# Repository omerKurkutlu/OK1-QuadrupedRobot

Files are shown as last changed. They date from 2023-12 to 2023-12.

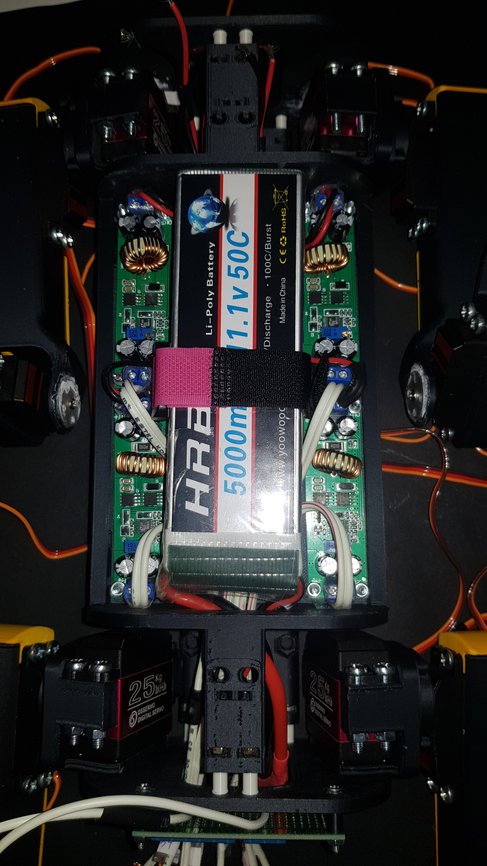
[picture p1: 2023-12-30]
media/3.jpg

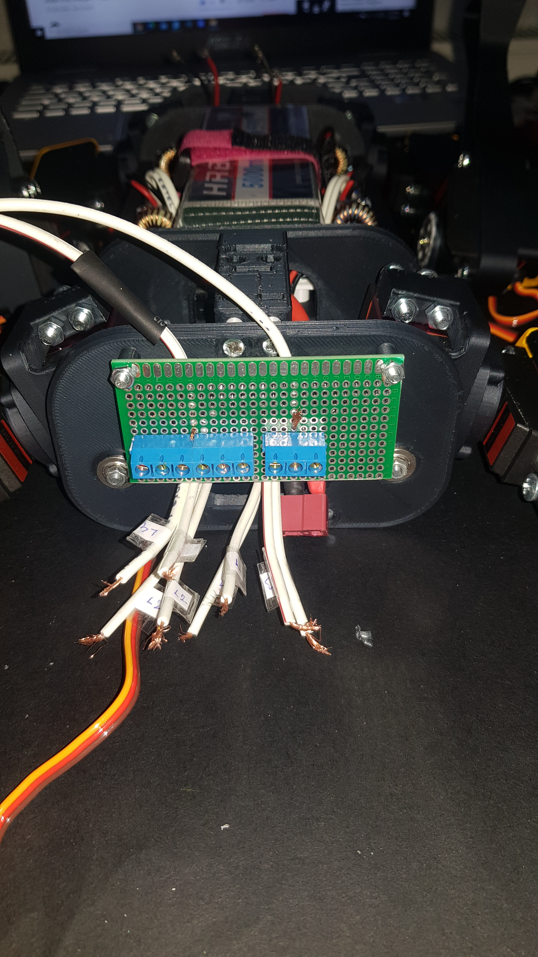
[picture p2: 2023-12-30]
media/4.jpg

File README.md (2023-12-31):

# Quadruped Robot Project

1. [Overview](#overview)
2. [Features](#features)
3. [Folder Structure](#folder-structure)
4. [Enjoying OK1 Robot (Video)](#enjoying-ok1-robot-video)
5. [Getting Started for ROS and Gazebo](#getting-started-for-ros-and-gazebo)
    - [Clone the Repository](#1-clone-the-repository)
    - [Navigate to the ROS Workspace](#2-navigate-to-the-ros-workspace)
    - [Build the ROS Workspace](#3-build-the-ros-workspace)
    - [Source the Workspace](#4-source-the-workspace)
    - [Launch the Robot](#5-launch-the-robot)
6. [OK1 Robot Simulation (Video)](#ok1-robot-simulation-video)
7. [3D Printing Files and Assembly Instructions](#3d-printing-files-and-assembly-instructions)
    - [OK1 Printings](#ok1-printings)
    - [Remote Controller Printings](#remote-controller-printings)
    - [ELECTRONICS for OK1](#electronics-for-ok1)
    - [ELECTRONICS for Remote Controller](#electronics-for-remote-controller)
    - [HARDWAREs](#hardwares)
    - [EXTERNALS](#externals)
8. [Electronics Assembly](#electronics-assembly)
9. [Wiring Instructions](#wiring-instructions)
10. [Arduino Code Compiling and Uploading](#arduino-code-compiling-and-uploading)
11. [Remote Controller Usage Instructions](#remote-controller-usage-instructions)

## Overview

This project implements a quadruped robot named OK1 using Arduino, with support for ROS and Gazebo simulation. The robot is designed to walk on four legs and can be controlled both physically and through software.

## Features

- Quadruped robot hardware based on Arduino Mega 2560.
- A Remote Controller
- ROS (Robot Operating System) support for high-level control and communication.
- Gazebo simulation environment for testing and development.
- Modular and extensible design for customization.

## Folder Structure

- **`/CAD-Hardware`**: Contains 3D printing files for the robot parts.
- **`/Arduino`**: Arduino code for controlling the robot.
- **`/ROS_ws`**: ROS packages for communication and control.
- **`/media`**: Some useful images for implementation.

render0

## Enjoying OK1 Robot (Video)

We are enjoying OK1 Robot. (https://www.youtube.com/watch?v=7ynvawNMwWk&ab_channel=%C3%96merKurkutlu)

## Getting Started for ROS and Gazebo

Follow these steps to get started with the ROS and Gazebo simulation environment for the OK1 Quadruped Robot:

1. **Clone the Repository:**

    ```bash
    git clone https://github.com/omerKurkutlu/OK1-QuadrupedRobot.git
    ```

2. **Navigate to the ROS Workspace:**

    ```bash
    cd ROS_ws
    ```

3. **Build the ROS Workspace:**

    ```bash
    catkin_make
    ```

4. **Source the Workspace:**

    ```bash
    source ./devel/setup.bash
    ```

5. **Launch the Robot:**

    - For Rviz Visualization:

        ```bash
        roslaunch ok1_moveit_config demo.launch
        ```

    - For Gazebo Simulation:

        ```bash
        roslaunch ok1_moveit_config demo_gazebo.launch
        ```

These commands will set up the necessary environment for ROS and Gazebo, allowing you to visualize and simulate the OK1 Quadruped Robot. Make sure to follow the instructions carefully, and feel free to explore the ROS workspace for additional details.
 
r1

## OK1 Robot Simulation (Video)
OK1 Robot - Quadruped Robot Gazebo Simulation (https://www.youtube.com/watch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)
OK1 Robot - Quadruped Robot based on ROS and MoveIt (https://www.youtube.com/watch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)

## 3D Printing Files and Assembly Instructions

You can find the 3D printing files in the designated folders. Feel free to explore the following directories:

- [Folder 1: OK1 Printing Files](https://github.com/omerKurkutlu/OK1-QuadrupedRobot/tree/main/CAD-Hardware/OK1-stl)
- [Folder 2: Remote Controller Printing Files](https://github.com/omerKurkutlu/OK1-QuadrupedRobot/tree/main/CAD-Hardware/Remote-stl)

Additionally, assembly instructions are available in a series of video tutorials. Follow the steps in the video series linked below:

[Assembly Video Series](https://www.youtube.com/watch?v=DqhxIvC9eWk&list=PLxYZuRPj6mQb903nfbroYomobq1NtwxHy&pp=gAQBiAQB)

[You can enjoy Solidworks Assembly Video Series](https://www.youtube.com/watch?v=uvvxWS9CNvI&list=PLxYZuRPj6mQaa-p4TQK3fZpWwg_Pw1YFy&pp=gAQBiAQB)

### OK1 Printings

| NO. | Part Name | QTY. |
| --- | --- | ---- |
| 1 | Chassis_Sholder_plate_Rear | 2 |
| 2 | Chassis_Sholder_plate_Front | 2 |
| 3 | Chassis_plate_for_electronics | 1 |
| 4 | Chassis_plate_for_battery | 1 |
| 5 | Chassis_side_plate_with_socket_hole  | 1 |
| 6 | Chassis_side_plate | 1 |
| 7 | Chassis_bridge_upper | 2 |
| 8 | Chassis_brigde_lower | 2 |
| 9 | cover_back | 1 |
| 10  | cover_front | 1 |
| 11  | cover_upper | 1 |
| 12  | cover_bottom | 1 |
| 13  | cover_face | 1 |
| 14  | Leg_lowerLeg_Left | 2 |
| 15  | Leg_UpperLeg_Left | 2 |
| 16  | Leg_upperLeg_ServoConnector_left | 2 |
| 17  | Chassis_sholder | 4 |
| 18  | shoe | 4 |
| 19  | cover_upperLeg_liner_R | 4 |
| 20  | Leg_lowerLeg_Right | 2 |
| 21  | Leg_UpperLeg_Right | 2 |
| 22  | Leg_upperLeg_ServoConnector_Right | 2 |
|  | NUMBER OF PARTS | 41 |

### Remote Controller Printings
| NO. | PART NAME | QTY. |
| --- | --- | ---  |
| 1 | Back_Cover | 1 |
| 2 | Remote_main_body_V2  | 1 |
| 3 | joystick_frame | 3 |
|  | NUMBER OF PARTS | 5 |

### ELECTRONICS for OK1
| NO. | PART NAME | QTY. |
| --- | --- | ---- |
| 1 | Arduino Mega 2560 | 1 |
| 2 | Relay Body | 2 |
| 3 | NRF_module | 1 |
| 4 | NRF_regulator | 1 |
| 5 | lm2596board | 1 |
| 6 | PowerDistributor | 1 |
| 7 | battery | 1 |
| 8 | Regulator 10A DC-DC | 4 |
| 9 | led | 6 |
| 10  | cam | 1 |
| 11  | Electronics_Switch | 1 |
| 12  | Servo-DS3225MG | 12 |
|  | NUMBER OF COMPONENTS | 32 |

### ELECTRONICS for Remote Controller
| NO. | PART NAME | QTY. |
| --- | --- | ---- |
| 1 | Arduino Mega 2560 | 1 |
| 2 | NRF_module | |
| 3 | NRF_regulator | 1 |
| 4 | Chassis-Front | 1 |
| 5 | Chassis-Back | 1 |
| 6 | lm2596 Board | 1 |
| 7 | PowerDistributor Board | 1 |
| 8 | battery 1.5 volt | 4 |
| 9 | Battery case | 1 |
| 10  | led(green&red) | 2 |
| 11  | Nokia Screen 5510 | 1 |
| 12  | Remote_Switch | 1 |
| 13  | JoyStick | 3 |
| 14  | Potansiometre | 2 |
| 15  | Buttons | 8 |
| 16  | Robot_switch | 1 |
| 17  | screws | 25 |

### HARDWAREs
| NO. | PART NAME | QTY. |
| --- | --- | ---- |
| 1 | nut | 4 |
| 2 | bearing | 8 |
| 3 | Servo-horn | 12 |
| 4 | screw-m3 | 30 |

### EXTERNALS
| NO. | PART NAME | QTY. |
| --- | --- | ---- |
| 1 | LiPo Charger | 1 |
| 2 | Box | 1 |
| 3 | Jumpers | 1 |
| 4 | Cables | 1 |

## Electronics Assembly

Below is a simplified Fritzing schema providing an overview of the electronics assembly for the OK1 Quadruped Robot project. Please note that this schema is incomplete and serves as a starting point. Refer to the detailed schematics and documentation for accurate connections.

ok1_v1_bb

You can also refer those images for electronics:

- [Image 1: OK1 Printing Files](https://github.com/omerKurkutlu/OK1-QuadrupedRobot/blob/main/media/1.jpg))
- [Image 2: OK1 Printing Files](https://github.com/omerKurkutlu/OK1-QuadrupedRobot/blob/main/media/2.jpg))
- [Image 3: OK1 Printing Files](https://github.com/omerKurkutlu/OK1-QuadrupedRobot/blob/main/media/3.jpg))
- [Image 4: OK1 Printing Files](https://github.com/omerKurkutlu/OK1-QuadrupedRobot/blob/main/media/4.jpg))

### Wiring Instructions

- Connect the components according to the Fritzing schema.
- Ensure proper power distribution and regulation.
- Check and cross-verify the connections with the detailed schematics.

## Arduino Code Compiling and Uploading

Before compiling and uploading the Arduino code for the OK1 Quadruped Robot, ensure that you have downloaded the required libraries. Follow these steps to set up and upload the code:

1. **Download Required Libraries:**

   Open the Arduino IDE and navigate to `Sketch > Include Library > Manage Libraries...`. In the Library Manager, search for and install the following libraries:

   - `Servo.h`
   - `MPU6050.h`
   - `Wire.h`
   - `PID_v1.h` (For self-balance which is not implemented in this version)
   - `SPI.h`
   - `nRF24L01.h`
   - `RF24.h`
   - `myServo_class.h` (Custom Library - No download required)
   - `Quadruped.h` (Custom Library - No download required)

   Make sure to install the specific versions of the libraries if mentioned in your project documentation.

1. **Open the Arduino Sketch:**

   Open the main Arduino sketch file located in the `/Arduino` directory of your project.

2. **Configure Arduino Board:**

   Go to `Tools > Board` and select the appropriate Arduino board. Ensure that the correct port is selected under `Tools > Port`.

3. **Verify and Upload:**

   - Click on the checkmark icon (`Verify`) to compile the code and check for any errors.
   - If the code compiles successfully, click on the right arrow icon (`Upload`) to upload the code to the Arduino board.

4. **Monitor Serial Output (Optional):**

   Open the Serial Monitor (`Tools > Serial Monitor`) to view debug information and status messages if your code includes serial communication.

5. **Troubleshooting:**

   If you encounter any issues during compilation or uploading, refer to the troubleshooting section in the project documentation or community forums.

Remember to customize the instructions based on the specific details of your project, including the names of libraries and any additional configurations users might need to make. If you have a specific troubleshooting section or documentation, it's a good idea to guide users there for more in-depth assistance.

## Remote controller usage instructions 
remote

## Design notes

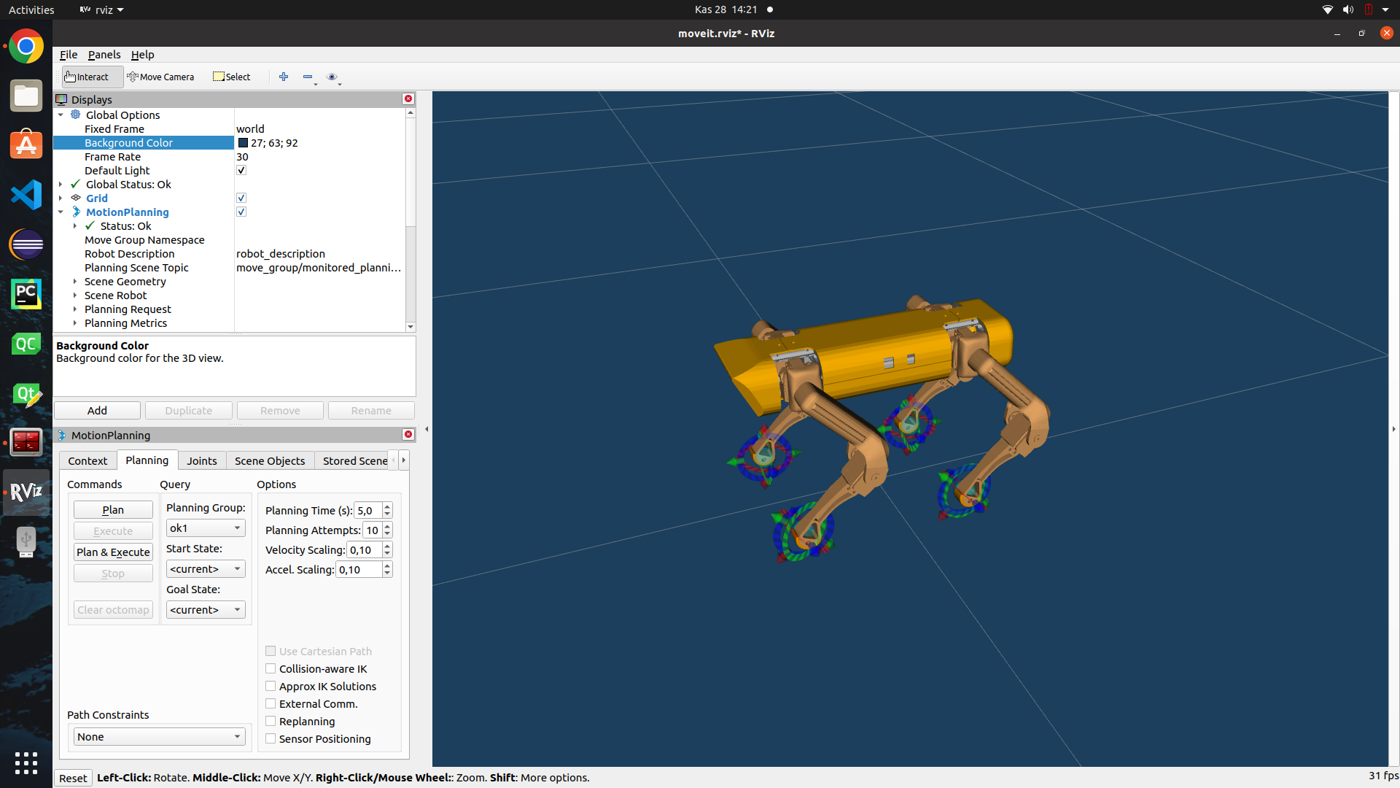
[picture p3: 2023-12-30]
media/r2.png

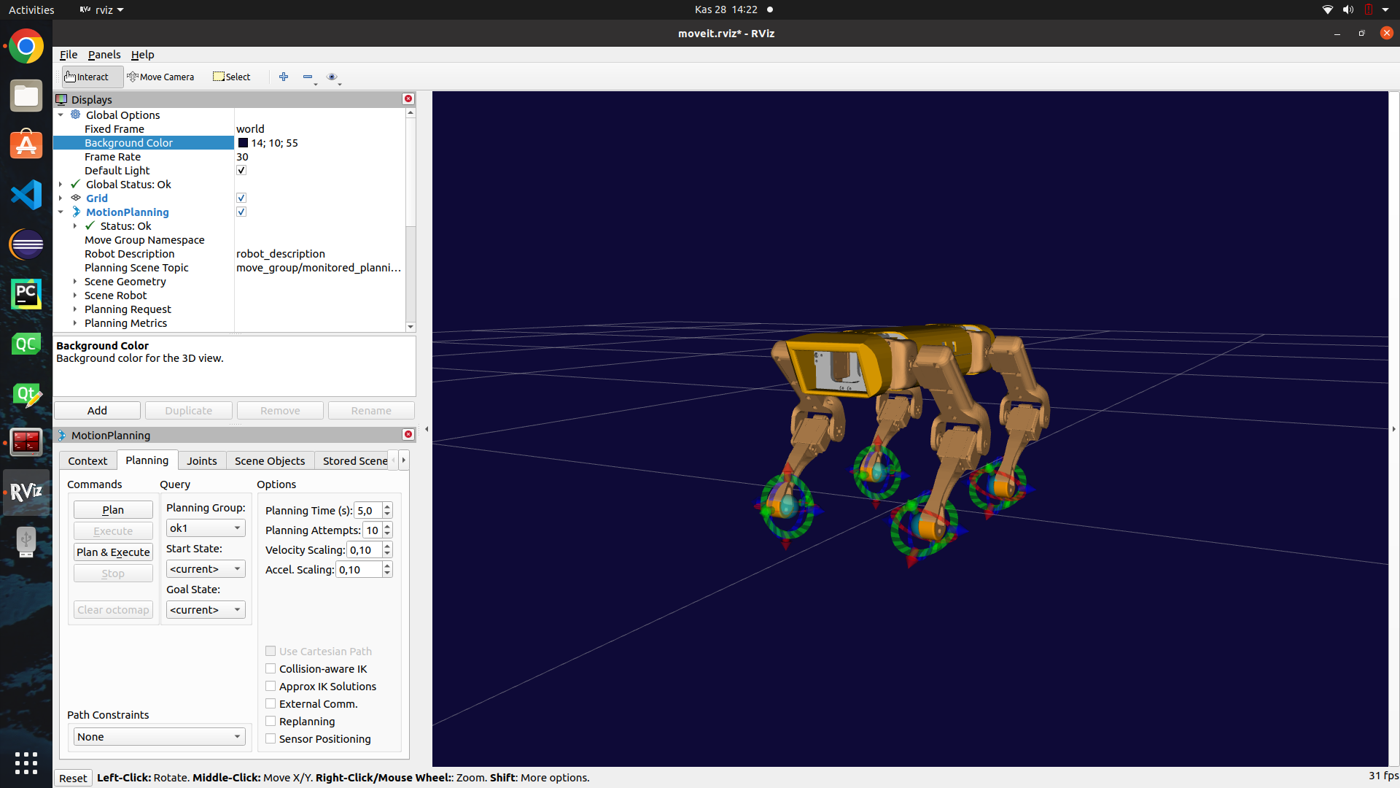
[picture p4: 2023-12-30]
media/r3.png

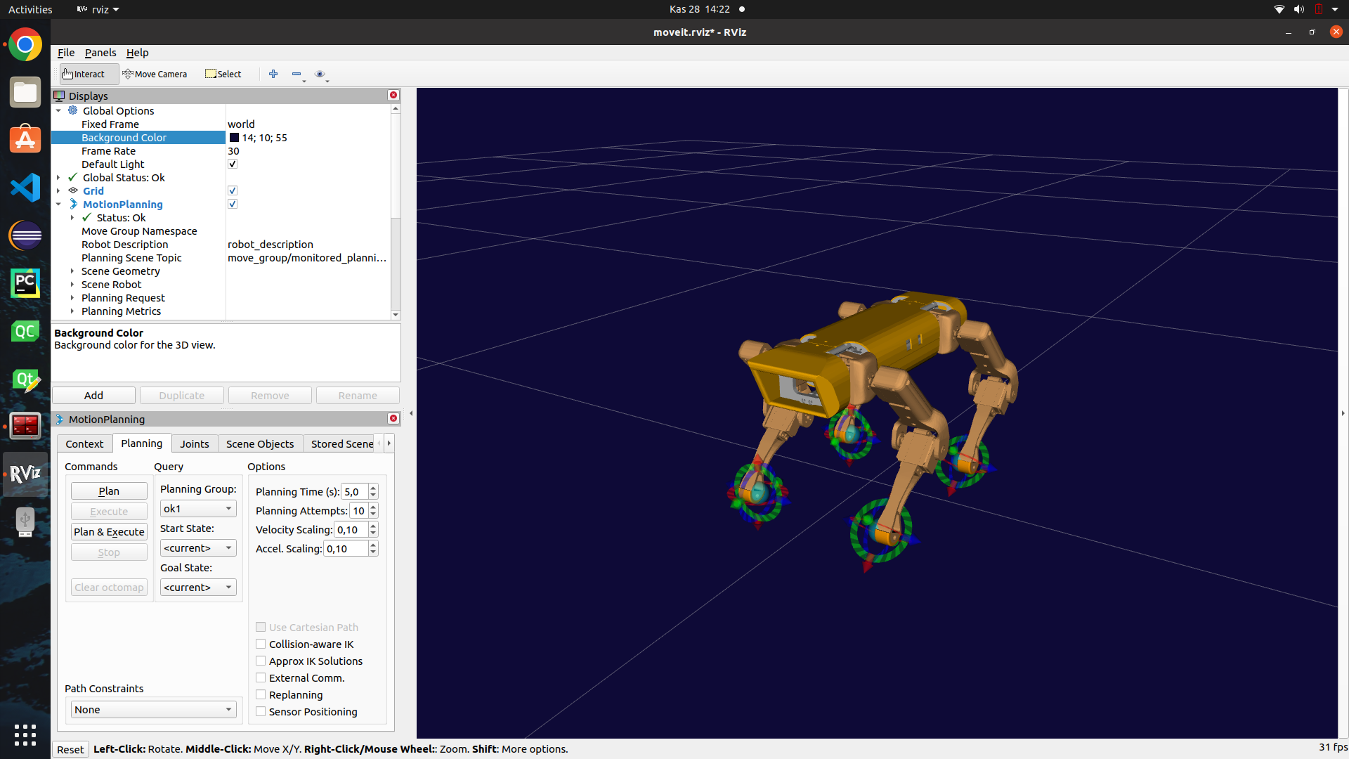
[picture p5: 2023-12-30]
media/r4.png

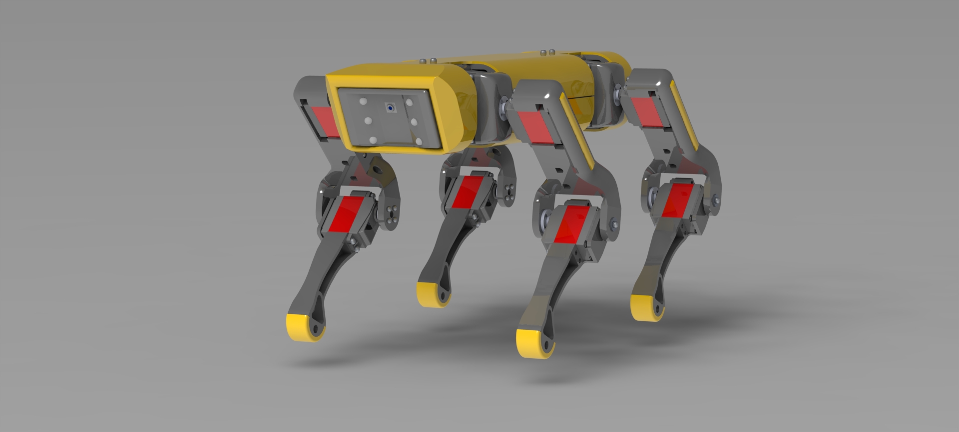
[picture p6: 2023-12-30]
media/render.JPG

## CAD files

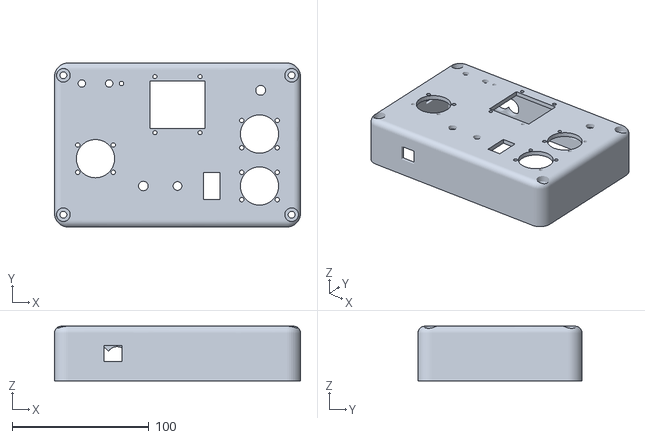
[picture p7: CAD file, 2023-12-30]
CAD-Hardware/Remote-stl/Remote_main_body_V2.STL
180.0 x 120.0 x 40.0

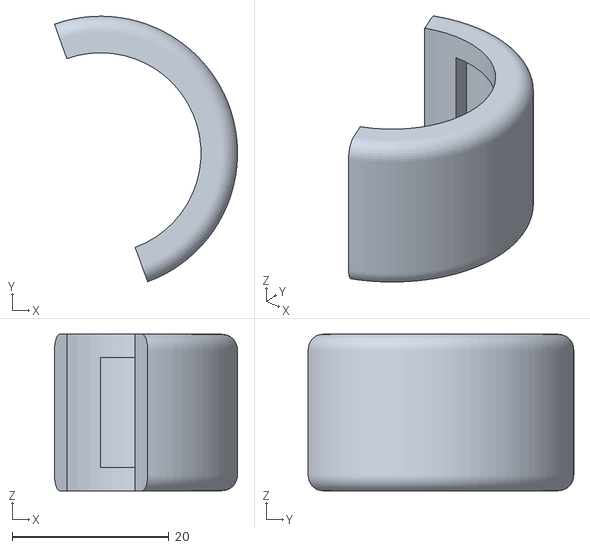
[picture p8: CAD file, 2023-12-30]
CAD-Hardware/OK1-stl/shoe.STL
23.4 x 33.9 x 20.0

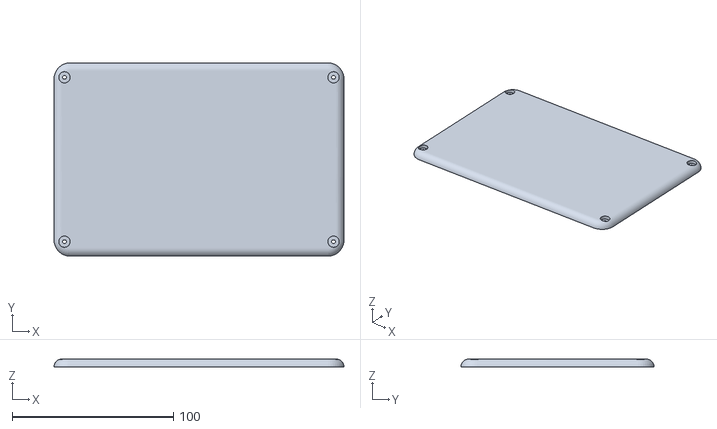
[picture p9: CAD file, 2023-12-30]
CAD-Hardware/Remote-stl/Back_Cover.STL
180.0 x 120.0 x 5.00

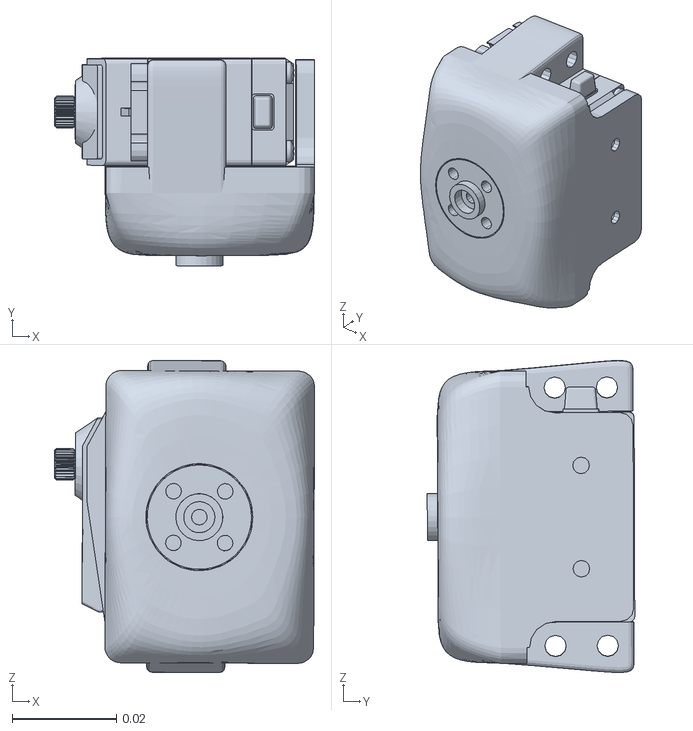
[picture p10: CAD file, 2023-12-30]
ROS_ws/src/ok1_description/meshes/leg3_sholder.STL
0.0499 x 0.0398 x 0.0598

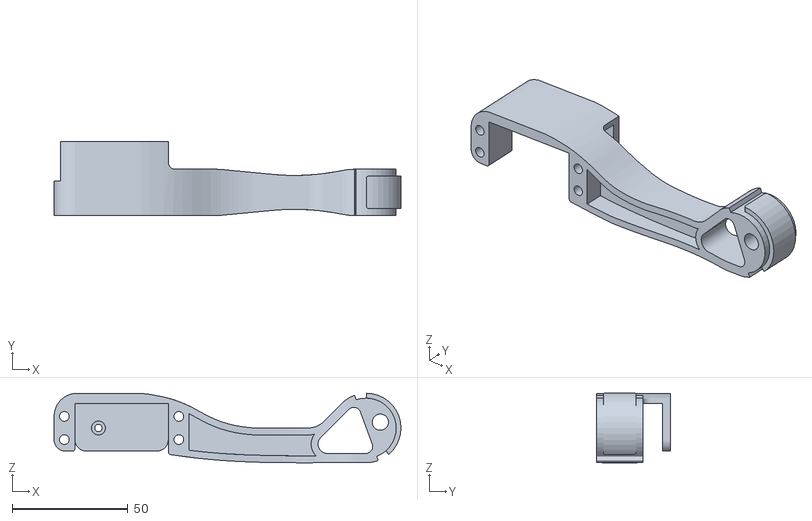
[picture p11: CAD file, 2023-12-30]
CAD-Hardware/OK1-stl/Leg_lowerLeg_Right.STL
149.9 x 32.0 x 30.0

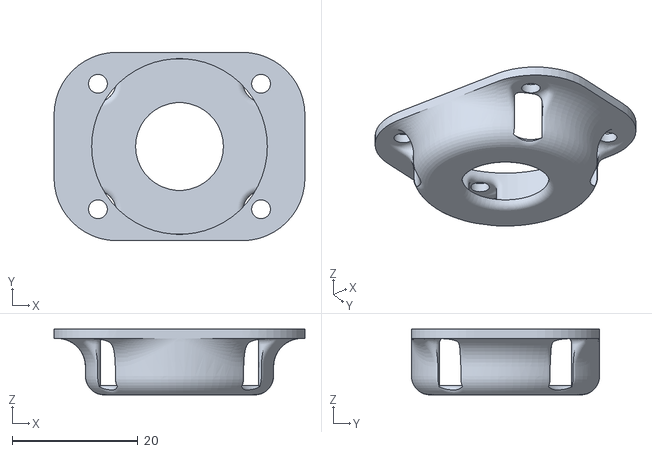
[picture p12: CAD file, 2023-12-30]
CAD-Hardware/Remote-stl/joystick_frame.STL
40.0 x 30.0 x 10.5

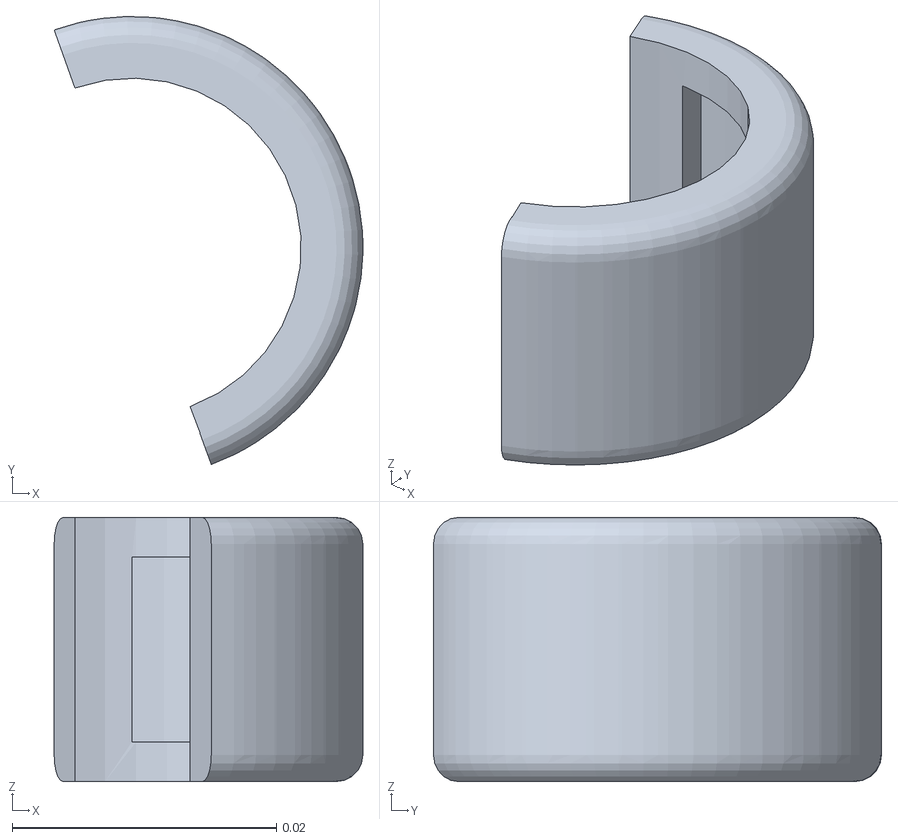
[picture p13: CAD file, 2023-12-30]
ROS_ws/src/ok1_description/meshes/leg2_shoe.STL
0.0234 x 0.0339 x 0.02

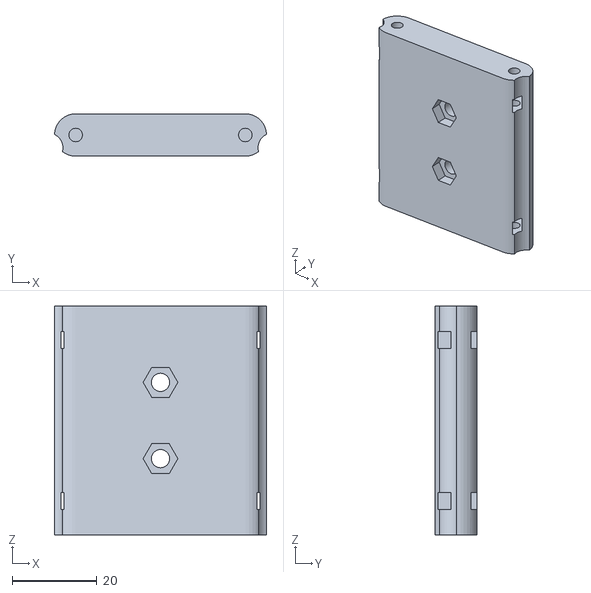
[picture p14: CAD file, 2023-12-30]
CAD-Hardware/OK1-stl/Chassis_bridge_upper.STL
50.0 x 10.0 x 54.0

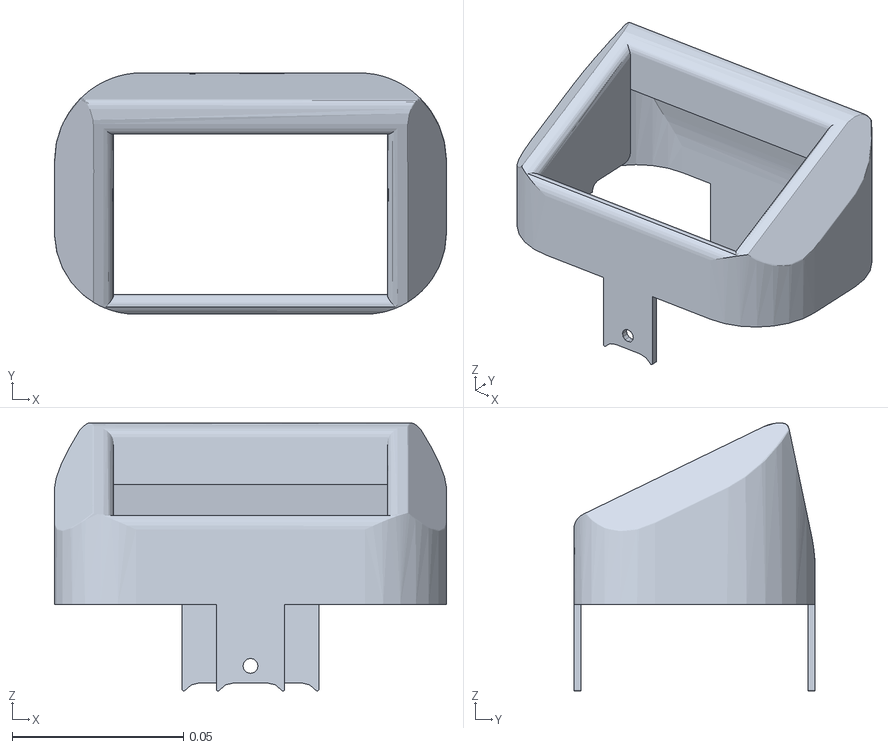
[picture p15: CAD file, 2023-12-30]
ROS_ws/src/ok1_description/meshes/cover_front.STL
0.115 x 0.0706 x 0.0783

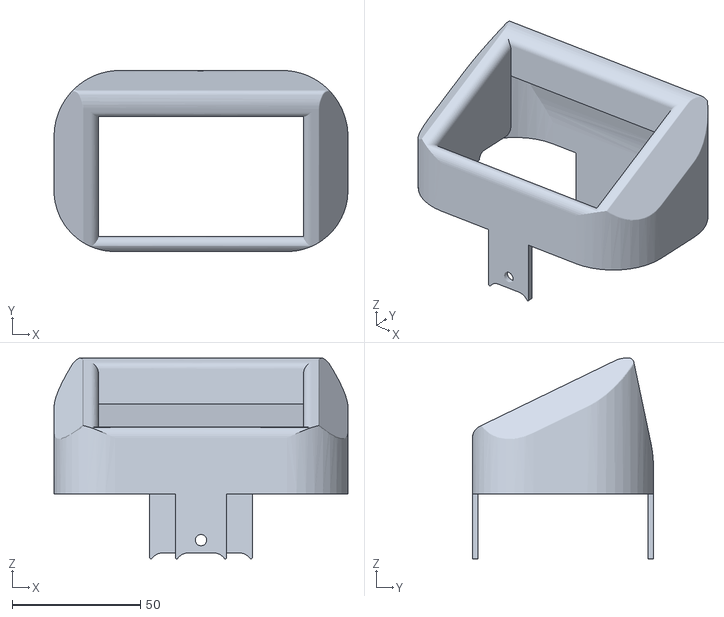
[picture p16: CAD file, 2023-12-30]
CAD-Hardware/OK1-stl/cover_front.STL
114.6 x 70.6 x 78.3

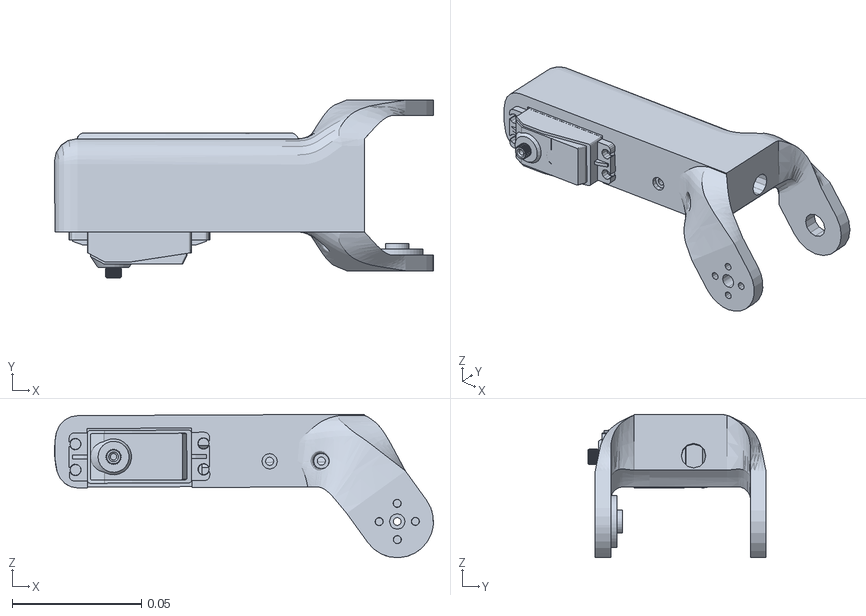
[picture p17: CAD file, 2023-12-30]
ROS_ws/src/ok1_description/meshes/leg4_upperLeg.STL
0.146 x 0.0688 x 0.0554

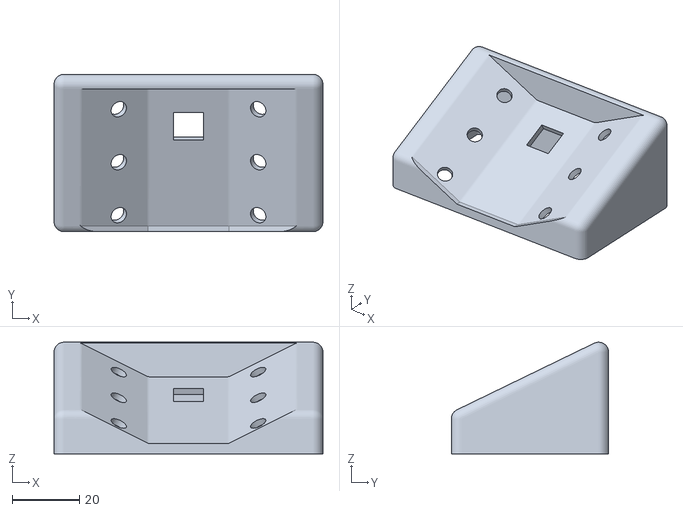
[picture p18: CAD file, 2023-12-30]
CAD-Hardware/OK1-stl/cover_face.STL
80.0 x 46.8 x 33.2

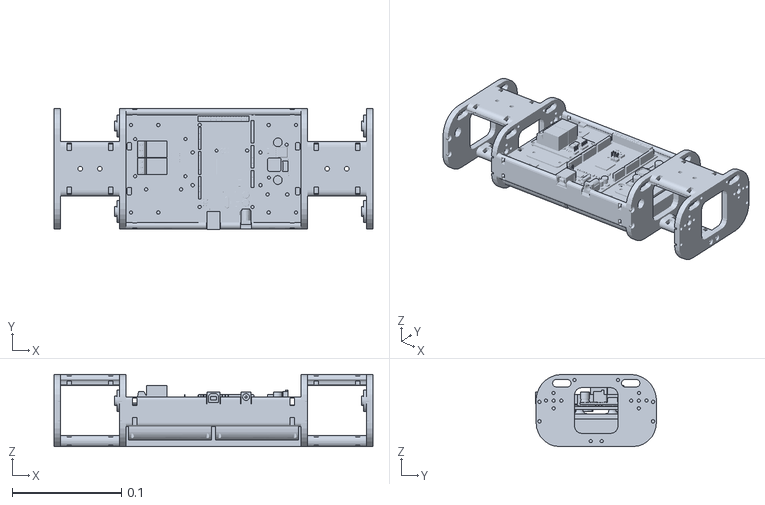
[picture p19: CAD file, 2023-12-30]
ROS_ws/src/ok1_description/meshes/body_link.STL
0.292 x 0.11 x 0.066

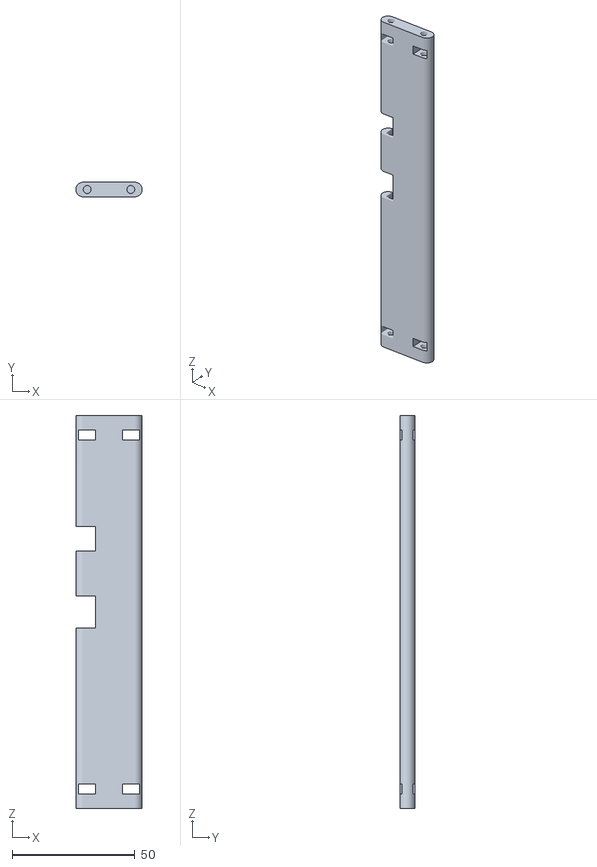
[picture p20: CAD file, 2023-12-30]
CAD-Hardware/OK1-stl/Chassis_side_plate_with_socket_hole.STL
27.0 x 6.00 x 160.0

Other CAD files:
ROS_ws/src/ok1_description/meshes/leg1_sholder.STL
ROS_ws/src/ok1_description/meshes/leg3_shoe.STL
CAD-Hardware/OK1-stl/Leg_lowerLeg_Left.STL
ROS_ws/src/ok1_description/meshes/leg2_upperLeg.STL
CAD-Hardware/OK1-stl/Chassis_Sholder_plate_Front.STL
CAD-Hardware/OK1-stl/Chassis_Sholder_plate_Rear.STL
CAD-Hardware/OK1-stl/Chassis_brigde_lower.STL
CAD-Hardware/OK1-stl/Chassis_plate_for_battery.STL
CAD-Hardware/OK1-stl/Chassis_plate_for_electronics.STL
CAD-Hardware/OK1-stl/Chassis_sholder.STL
CAD-Hardware/OK1-stl/Chassis_side_plate.STL
CAD-Hardware/OK1-stl/Leg_UpperLeg_Left.STL
CAD-Hardware/OK1-stl/Leg_UpperLeg_Right.STL
CAD-Hardware/OK1-stl/Leg_upperLeg_ServoConnector_Right.STL
CAD-Hardware/OK1-stl/Leg_upperLeg_ServoConnector_left.STL
CAD-Hardware/OK1-stl/cover_back.STL
CAD-Hardware/OK1-stl/cover_upper.STL
CAD-Hardware/OK1-stl/cover_upperLeg_liner_R.STL
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

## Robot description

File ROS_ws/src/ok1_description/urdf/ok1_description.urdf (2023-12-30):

<?xml version="1.0" encoding="utf-8" ?>
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
<robot name="ok1_description">
    <link name="body_link">
        
<inertial>
            <origin xyz="-0.000289230415305888 0.000249411598945454 0.187980731962265" rpy="0 0 0" />
            <mass value="0.666709487101566" />
            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
        </inertial>

        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
    </link>
    <link name="leg1_sholder">
        
<inertial>
            <origin xyz="-0.0100797996076242 -0.00825373387628797 -0.00980713437986327" rpy="0 0 0" />
            <mass value="0.0738318074656321" />
            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
        </inertial>

        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
    </link>
    <joint name="leg1_sholder_joint" type="continuous">
        <origin xyz="0.0995397271888414 0.039000000000001 0.204530000000001" rpy="-0.00328404923919971 -0.00366189363205534 -3.14158062773443" />
        <parent link="body_link" />
        <child link="leg1_sholder" />
        <axis xyz="0.999993295202696 0 -0.0036619051945618" />
    </joint>
    <link name="leg1_upperLeg">
        
<inertial>
            <origin xyz="0.0452792232423253 -0.0334191491253542 0.000339191016331182" rpy="0 0 0" />
            <mass value="0.133370989032647" />
            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
        </inertial>

        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
    </link>
    <joint name="leg1_upperLeg_joint" type="continuous">
        <origin xyz="-0.0106969449547786 -0.0269671783926309 -0.00999951076746555" rpy="0.0046694621549828 0.790773853694313 0.00330749615393403" />
        <parent link="leg1_sholder" />
        <child link="leg1_upperLeg" />
        <axis xyz="0 1 0" />
    </joint>
    <link name="leg1_lowerLeg">
        
<inertial>
            <origin xyz="0.000429565936262033 -0.0283722783636612 -0.031315595489188" rpy="0 0 0" />
            <mass value="0.0659083879166162" />
            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
        </inertial>

        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
    </link>
    <joint name="leg1_lowerLeg_joint" type="continuous">
        <origin xyz="0.109493678029156 -0.0108000000000003 -0.0253117951091679" rpy="0 -0.000825326475181663 0" />
        <parent link="leg1_upperLeg" />
        <child link="leg1_lowerLeg" />
        <axis xyz="0 1 0" />
    </joint>
    <link name="leg1_shoe">
        
<inertial>
            <origin xyz="0.00652423030663664 0.00266149687275634 0.0100000000000001" rpy="0 0 0" />
            <mass value="0.00331613062793773" />
            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
        </inertial>

        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
    </link>
    <joint name="leg1_shoe_joint_fixed" type="fixed">
        <origin xyz="0.000589525911829744 -0.0178000000001228 -0.117942205677224" rpy="1.5707963267954 1.5562513086388 0" />
        <parent link="leg1_lowerLeg" />
        <child link="leg1_shoe" />
        <axis xyz="0 0 0" />
    </joint>
    <link name="leg2_sholder">
        
<inertial>
            <origin xyz="-0.0100438192282825 0.00836741230603254 -0.00974756844305564" rpy="0 0 0" />
            <mass value="0.073831807465632" />
            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
        </inertial>

        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
    </link>
    <joint name="leg2_sholder_joint" type="continuous">
        <origin xyz="0.0995397271888414 -0.038999999999999 0.20453" rpy="-0.00832062433548992 0 -3.14159265358978" />
        <parent link="body_link" />
        <child link="leg2_sholder" />
        <axis xyz="1 0 0" />
    </joint>
    <link name="leg2_upperLeg">
        
<inertial>
            <origin xyz="0.0453516729072076 0.0334198832097389 0.000470285466705023" rpy="0 0 0" />
            <mass value="0.133373382672251" />
            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
        </inertial>

        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
    </link>
    <joint name="leg2_upperLeg_joint" type="continuous">
        <origin xyz="-0.0106602559735094 0.0270818546194537 -0.00972500130406427" rpy="0.0118214582116251 0.789970926671989 0.00839736341152224" />
        <parent link="leg2_sholder" />
        <child link="leg2_upperLeg" />
        <axis xyz="0 1 0" />
    </joint>
    <link name="leg2_lowerLeg">
        
<inertial>
            <origin xyz="0.00040180607625448 0.0283723893074776 -0.0312645968917846" rpy="0 0 0" />
            <mass value="0.0659096193564579" />
            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
        </inertial>

        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
    </link>
    <joint name="leg2_lowerLeg_joint" type="continuous">
        <origin xyz="0.109666332997159 0.0107999999999999 -0.0249949576306193" rpy="0 -0.00460769933465639 0" />
        <parent link="leg2_upperLeg" />
        <child link="leg2_lowerLeg" />
        <axis xyz="0 1 0" />
    </joint>
    <link name="leg2_shoe">
        
<inertial>
            <origin xyz="0.00652423030663671 0.00266149687275635 0.01" rpy="0 0 0" />
            <mass value="0.00331613062793772" />
            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
        </inertial>

        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
    </link>
    <joint name="leg2_shoe_joint_fixed" type="fixed">
        <origin xyz="0.00103389302339335 0.0178000000001247 -0.117735366628566" rpy="-1.57079632679489 0.863252906301781 0" />
        <parent link="leg2_lowerLeg" />
        <child link="leg2_shoe" />
        <axis xyz="0 0 0" />
    </joint>
    <link name="leg3_sholder">
        
<inertial>
            <origin xyz="0.0285906233719435 -0.00825373387628808 -0.0099487427521034" rpy="0 0 0" />
            <mass value="0.0738318074656322" />
            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
        </inertial>

        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
    </link>
    <joint name="leg3_sholder_joint" type="continuous">
        <origin xyz="-0.0877895905525046 0.0389999999999991 0.20453" rpy="-0.00328404923919971 -0.00366189363205534 -3.14158062773443" />
        <parent link="body_link" />
        <child link="leg3_sholder" />
        <axis xyz="0.999993295202696 0 -0.0036619051945618" />
    </joint>
    <link name="leg3_upperLeg">
        
<inertial>
            <origin xyz="0.0452792232423253 -0.0334191491253545 0.000339191016331258" rpy="0 0 0" />
            <mass value="0.133370989032647" />
            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
        </inertial>

        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
    </link>
    <joint name="leg3_upperLeg_joint" type="continuous">
        <origin xyz="0.0279734780247891 -0.0269671783926307 -0.0101411191397053" rpy="0.0046694621549828 0.790773853694313 0.00330749615393497" />
        <parent link="leg3_sholder" />
        <child link="leg3_upperLeg" />
        <axis xyz="0 1 0" />
    </joint>
    <link name="leg3_lowerLeg">
        
<inertial>
            <origin xyz="0.000429565936262449 -0.0283722783636618 -0.0313155954891775" rpy="0 0 0" />
            <mass value="0.0659083879166247" />
            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
        </inertial>

        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
    </link>
    <joint name="leg3_lowerLeg_joint" type="continuous">
        <origin xyz="0.109493678029156 -0.0108000000000005 -0.0253117951091679" rpy="0 -0.000825326475181663 0" />
        <parent link="leg3_upperLeg" />
        <child link="leg3_lowerLeg" />
        <axis xyz="0 1 0" />
    </joint>
    <link name="leg3_shoe">
        
<inertial>
            <origin xyz="0.0065242303066366 0.00266149687275638 0.01" rpy="0 0 0" />
            <mass value="0.00331613062793771" />
            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
        </inertial>

        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
    </link>
    <joint name="leg3_shoe_joint_fixed" type="fixed">
        <origin xyz="0.000589525911828731 -0.0178000000001217 -0.117942205677204" rpy="1.57079632679544 1.55625130863879 0" />
        <parent link="leg3_lowerLeg" />
        <child link="leg3_shoe" />
        <axis xyz="0 0 0" />
    </joint>
    <link name="leg4_sholder">
        
<inertial>
            <origin xyz="0.028416436745352 0.00836741230603257 -0.00974756844305578" rpy="0 0 0" />
            <mass value="0.0738318074656321" />
            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
        </inertial>

        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
    </link>
    <joint name="leg4_sholder_joint" type="continuous">
        <origin xyz="-0.0880000168375241 -0.0390000000000009 0.20453" rpy="-0.00832062433548992 0 -3.14159265358978" />
        <parent link="body_link" />
        <child link="leg4_sholder" />
        <axis xyz="1 0 0" />
    </joint>
    <link name="leg4_upperLeg">
        
<inertial>
            <origin xyz="0.0453516729072075 0.0334198832097389 0.000470285466704967" rpy="0 0 0" />
            <mass value="0.133373382672251" />
            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
        </inertial>
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

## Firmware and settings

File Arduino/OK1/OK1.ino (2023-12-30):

#include<Servo.h>
#include<MPU6050.h> // SLC and SDA pins connect to respected pin in Arduino 
#include<Wire.h>
#include <PID_v1.h>
#include <SPI.h>
#include <nRF24L01.h>
#include <RF24.h>
#include "myServo_class.h" // to calculate the pre/curr/next position of servos
#include "Quadruped.h"

#define led1 22
#define led2 23
#define led3 24
#define led4 25
#define led5 26
#define led6 27

int controlBeforeRadio=0;  // Print received sensor values from Remote & imu

int delayForServos=7;

myServo s[12];
int* servoAngles; //to read servo anngles from Quadruped class we ned to use referance

MPU6050 mpu;

// Radio 
RF24 radio(40,42); // CE, CSN
const byte addresses[][6] = {"00001", "00002"};
float data[8];

//lipo battety level
float vPower=4.5;   // lipododan arduinoya gelen volt benimki icin 5.3 olmali 
float r1=2200;
float r2=220;

//valiables for IMU
int acceX,acceY,acceZ,gyroX,gyroY,gyroZ;
int previous_acceX=0;
int previous_acceY=0;

unsigned long previousTime=0;
unsigned long currentTime=0;
unsigned long previousWalkTime=0;
unsigned long previousSafetyTime=0; // for radio singal control
unsigned long loopBegin,loopEnd;
// received sensor values from Remote
float servoPower=0;
float high=3;   
float x_axis=0;
float y_axis=0;
float yaw=0;        // it gives angle to rotate
float pitch=0;      // it gives cm
float roll=0;       // it gives cm
float elevation=15;


#define relay1 14
#define relay2 15

Quadruped Quad(11.5,12); 

void setup() {
  Serial.begin(9600);
  
  //setup radio
  radio.begin();
  delay(100);
  radio.openWritingPipe(addresses[0]); // 00001
  radio.openReadingPipe(1, addresses[1]); // 00002
  radio.setPALevel(RF24_PA_MIN);
  delay(50);
  
  //setup IMU
  Wire.begin();
  mpu.initialize();
  
  //setup pins
  pinMode(A0,INPUT); // Battery Level
  pinMode(relay1,OUTPUT);
  pinMode(relay2,OUTPUT);

  
  //initial values
  digitalWrite(relay1,LOW);
  digitalWrite(relay2,LOW);

  //LEDs are ON
  digitalWrite(led1,HIGH);
  digitalWrite(led2,HIGH);
  digitalWrite(led3,HIGH);
  digitalWrite(led4,HIGH);
  digitalWrite(led5,HIGH);
  digitalWrite(led6,HIGH);
  
  servoAngles=Quad.signalValues();
  for(int i=0;i<12;i++)
      {
        
        s[i].setPin(i+2);            //set pin number 
        s[i].setOffset(servoAngles[i]);  // drive servo to offset position
        s[i].currentAngle=servoAngles[i];     // initialy currAng is set to offset
        s[i].setTargetAngle(servoAngles[i]);     // initialy currAng is set to offset
        //Serial.print("servo ");Serial.print(i+1);Serial.print("= ");Serial.println(s[i].targetAngle);
      }
   //execute(servoAngles);  // we can't execute because Relays are off...!
  delay(100);
}

void loop() {
  
  loopBegin=currentTime=millis();
  
  if(currentTime-previousTime>=10)
  {
    previousTime=currentTime;

    //Read Radio Data
    radio.startListening();
    if (radio.available())
    {
      radio.read(&data, sizeof(data));
      previousSafetyTime=currentTime;

      servoPower=data[0];
      high=data[1];   
      x_axis=data[2];
      y_axis=data[3];
      roll=data[4];
      pitch=data[5];
      yaw=data[6];
      elevation=data[7];
    }
    delay(3);
    
    // check whether remote disconnected
    if(currentTime-previousSafetyTime>=3000)
    {
      Serial.println("*no remote data* ");
      previousSafetyTime=currentTime;
      // set everthing to offset value
    }
  
    //Read IMI values
    mpu.getAcceleration(&acceX,&acceY,&acceZ);
    mpu.getRotation(&gyroX,&gyroY,&gyroZ);
    
    acceX=map(acceX,-17000,17000,-90,90);
    if(abs(previous_acceX-acceX)>=15)
    {
      previous_acceX=acceX;
    }
    else
    {
      acceX=previous_acceX;
    } 
    acceX=acceX/5; 
    //if(acceX>=-1 && acceX<=1) acceX=0;  
    
    
    acceY=map(acceY,-17000,17000,90,-90);
    if(acceY>=-3 && acceY<=3) acceY=0;
    
    // sent t battary level to remote
    radio.stopListening();
    float v=(analogRead(0)*vPower)/1024.0;
    float volt=v/(r2/(r1+r2));
    radio.write(&volt, sizeof(volt));
    delay(3);

    /*
     * code there
     */
    if(servoPower==1)
    {
     digitalWrite(relay1,HIGH);
     digitalWrite(relay2,HIGH);
    }
    else
    {
     digitalWrite(relay1,LOW);
     digitalWrite(relay2,LOW);
    }
    
    Quad.setVariables(x_axis,y_axis,roll,pitch,yaw,elevation,high,acceX,acceY);
    //Quad.displayVariables();
    servoAngles=Quad.signalValues();

    fireServoSignal(servoAngles);

    if(controlBeforeRadio==1) sensorDatas(); //print remote/ imu / sensors data
 
  }// end time-loop

  //delay(1000);
  
  loopEnd=millis();
  //Serial.print("Loop Time"); Serial.println(loopEnd-loopBegin);
}//end void loop

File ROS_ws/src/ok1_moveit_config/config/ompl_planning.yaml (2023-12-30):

planner_configs:
  AnytimePathShortening:
    type: geometric::AnytimePathShortening
    shortcut: true  # Attempt to shortcut all new solution paths
    hybridize: true  # Compute hybrid solution trajectories
    max_hybrid_paths: 24  # Number of hybrid paths generated per iteration
    num_planners: 4  # The number of default planners to use for planning
    planners: ""  # A comma-separated list of planner types (e.g., "PRM,EST,RRTConnect"Optionally, planner parameters can be passed to change the default:"PRM[max_nearest_neighbors=5],EST[goal_bias=.5],RRT[range=10. goal_bias=.1]"
  SBL:
    type: geometric::SBL
    range: 0.0  # Max motion added to tree. ==> maxDistance_ default: 0.0, if 0.0, set on setup()
  EST:
    type: geometric::EST
    range: 0.0  # Max motion added to tree. ==> maxDistance_ default: 0.0, if 0.0 setup()
    goal_bias: 0.05  # When close to goal select goal, with this probability. default: 0.05
  LBKPIECE:
    type: geometric::LBKPIECE
    range: 0.0  # Max motion added to tree. ==> maxDistance_ default: 0.0, if 0.0, set on setup()
    border_fraction: 0.9  # Fraction of time focused on boarder default: 0.9
    min_valid_path_fraction: 0.5  # Accept partially valid moves above fraction. default: 0.5
  BKPIECE:
    type: geometric::BKPIECE
    range: 0.0  # Max motion added to tree. ==> maxDistance_ default: 0.0, if 0.0, set on setup()
    border_fraction: 0.9  # Fraction of time focused on boarder default: 0.9
    failed_expansion_score_factor: 0.5  # When extending motion fails, scale score by factor. default: 0.5
    min_valid_path_fraction: 0.5  # Accept partially valid moves above fraction. default: 0.5
  KPIECE:
    type: geometric::KPIECE
    range: 0.0  # Max motion added to tree. ==> maxDistance_ default: 0.0, if 0.0, set on setup()
    goal_bias: 0.05  # When close to goal select goal, with this probability. default: 0.05
    border_fraction: 0.9  # Fraction of time focused on boarder default: 0.9 (0.0,1.]
    failed_expansion_score_factor: 0.5  # When extending motion fails, scale score by factor. default: 0.5
    min_valid_path_fraction: 0.5  # Accept partially valid moves above fraction. default: 0.5
  RRT:
    type: geometric::RRT
    range: 0.0  # Max motion added to tree. ==> maxDistance_ default: 0.0, if 0.0, set on setup()
    goal_bias: 0.05  # When close to goal select goal, with this probability? default: 0.05
  RRTConnect:
    type: geometric::RRTConnect
    range: 0.0  # Max motion added to tree. ==> maxDistance_ default: 0.0, if 0.0, set on setup()
  RRTstar:
    type: geometric::RRTstar
    range: 0.0  # Max motion added to tree. ==> maxDistance_ default: 0.0, if 0.0, set on setup()
    goal_bias: 0.05  # When close to goal select goal, with this probability? default: 0.05
    delay_collision_checking: 1  # Stop collision checking as soon as C-free parent found. default 1
  TRRT:
    type: geometric::TRRT
    range: 0.0  # Max motion added to tree. ==> maxDistance_ default: 0.0, if 0.0, set on setup()
    goal_bias: 0.05  # When close to goal select goal, with this probability? default: 0.05
    max_states_failed: 10  # when to start increasing temp. default: 10
    temp_change_factor: 2.0  # how much to increase or decrease temp. default: 2.0
    min_temperature: 10e-10  # lower limit of temp change. default: 10e-10
    init_temperature: 10e-6  # initial temperature. default: 10e-6
    frountier_threshold: 0.0  # dist new state to nearest neighbor to disqualify as frontier. default: 0.0 set in setup()
    frountierNodeRatio: 0.1  # 1/10, or 1 nonfrontier for every 10 frontier. default: 0.1
    k_constant: 0.0  # value used to normalize expresssion. default: 0.0 set in setup()
  PRM:
    type: geometric::PRM
    max_nearest_neighbors: 10  # use k nearest neighbors. default: 10
  PRMstar:
    type: geometric::PRMstar
  FMT:
    type: geometric::FMT
    num_samples: 1000  # number of states that the planner should sample. default: 1000
    radius_multiplier: 1.1  # multiplier used for the nearest neighbors search radius. default: 1.1
    nearest_k: 1  # use Knearest strategy. default: 1
    cache_cc: 1  # use collision checking cache. default: 1
    heuristics: 0  # activate cost to go heuristics. default: 0
    extended_fmt: 1  # activate the extended FMT*: adding new samples if planner does not finish successfully. default: 1
  BFMT:
    type: geometric::BFMT
    num_samples: 1000  # number of states that the planner should sample. default: 1000
    radius_multiplier: 1.0  # multiplier used for the nearest neighbors search radius. default: 1.0
    nearest_k: 1  # use the Knearest strategy. default: 1
    balanced: 0  # exploration strategy: balanced true expands one tree every iteration. False will select the tree with lowest maximum cost to go. default: 1
    optimality: 1  # termination strategy: optimality true finishes when the best possible path is found. Otherwise, the algorithm will finish when the first feasible path is found. default: 1
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

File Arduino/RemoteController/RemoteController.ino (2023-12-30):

#include <SPI.h>
#include <nRF24L01.h>
#include <RF24.h>

RF24 radio(48,49); // CE, CSN
const byte addresses[][6] = {"00001", "00002"};
float data[8];
float message;

unsigned long previousTime=0;
unsigned long currentTime=0;
unsigned long previousSafetyTime=0;

int controlBeforeRadio=0;  // Print received sensor values from Remote

float servoPower=0;
float high=0;
float x_axis=0;
float y_axis=0;
float roll=0;
float pitch=0;
float yaw=0;
float elevation=0;
#define greenLed 3
#define redLed 4


void setup() {
  pinMode(2,INPUT);  // servo power
  pinMode(A0,INPUT);  //x-axis
  pinMode(A1,INPUT);  //y-axis
  pinMode(A2,INPUT);  //pitch
  pinMode(A3,INPUT);  //roll
  pinMode(A4,INPUT);  //yaw
  pinMode(A5,INPUT);  // elevation
  pinMode(A6,INPUT);  // Speed
  pinMode(greenLed,OUTPUT);  //greenLED
  pinMode(redLed,OUTPUT);  //redLED

  servoPower=0;
  high=3;
  x_axis=0;
  y_axis=0;
  yaw=0;
  pitch=0;
  roll=0;
  elevation=7;
  
  Serial.begin(9600);
  delay(100);
  radio.begin();
  delay(100);
  radio.openWritingPipe(addresses[1]); // 00002
  radio.openReadingPipe(1, addresses[0]); // 00001
  radio.setPALevel(RF24_PA_MIN);

  digitalWrite(greenLed,LOW);    // green led is low
  digitalWrite(redLed,HIGH);   // red led is high
  delay(100);
}

void loop() {
  currentTime=millis();
  if(currentTime-previousTime>=10) //10
  {
    previousTime=currentTime;
    
    radio.stopListening();
    
    servoPower=digitalRead(2); 
    x_axis=range(analogRead(A0),0,1023,5,-5);  if(x_axis>=-0.3 && x_axis<=0.3) x_axis=0;
    y_axis=range(analogRead(A1),1023,0,2.5,-2.5);    if(y_axis>=-0.3 && y_axis<=0.3) y_axis=0;
    roll=range(analogRead(A2),1023,0,-5,5);   if(roll>=-0.4 && roll<=0.4) roll=0;
    pitch=range(analogRead(A3),0,1023,7,-7);  if(pitch>=-0.5 && pitch<=0.5) pitch=0;    
    yaw=range(analogRead(A4),1023,0,3,-3);  if(yaw>=-0.3 && yaw<=0.3) yaw=0;
    //yaw=range(analogRead(A4),1023,0,30,-30);  if(yaw>=-2 && yaw<=2) yaw=0;
    elevation=range(analogRead(A5),0,1023,0,23.5); // this must be between min=6 (reality is 8) and max=leg_length
    high=range(analogRead(A6),0,1023,2,4);
    data[0]=servoPower;
    data[1]=high;
    data[2]=x_axis;
    data[3]=y_axis;
    data[4]=roll;
    data[5]=pitch;
    data[6]=yaw;
    data[7]=elevation;
    radio.write(&data, sizeof(data));
    delay(3);

    radio.startListening();
    if(radio.available())
    {
      digitalWrite(redLed,LOW);
      digitalWrite(greenLed,HIGH);
      radio.read(&message, sizeof(message));
      //Serial.print("Battery Level=");   Serial.println(message); 
      previousSafetyTime=currentTime;
    }
    if(currentTime-previousSafetyTime>=1500)
    {
      //Serial.println("*no remote data* ");
      digitalWrite(redLed,HIGH);
      digitalWrite(greenLed,LOW);
      previousSafetyTime=currentTime;
    }
    delay(3);
    if(controlBeforeRadio==1) printInputValues(); 
  }  
}


void printInputValues()
{
  Serial.print("  servoPower=");  
  Serial.print(servoPower); 
  Serial.print("  x_axis="); 
  Serial.print(x_axis);
  Serial.print("  y_axis="); 
  Serial.print(y_axis);
  Serial.print("  pitch="); 
  Serial.print(pitch);
  Serial.print("  roll="); 
  Serial.print(roll);
  Serial.print("  yaw="); 
  Serial.print(yaw);
  Serial.print("  elevation="); 
  Serial.print(elevation);
  Serial.print("  Speed="); 
  Serial.println(high);
}

float range(float x, float in_min, float in_max, float out_min, float out_max)
{
  return (x - in_min) * (out_max - out_min) / (in_max - in_min) + out_min;
}

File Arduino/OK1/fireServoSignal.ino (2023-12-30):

void fireServoSignal(int cycle[])
{
    int maxDiff=0;
        
    for(int i=0;i<12;i++)                // set the target angles
    {
      s[i].setTargetAngle(cycle[i]);
    }
    
     
    for(int i=0;i<12;i++)                             // find the time interval 
    {
      if(s[i].absDiff>maxDiff)  maxDiff=s[i].absDiff;
    }
   // Serial.println(maxDiff);

  int angles[12];             // we store current angle in different variable
  for(int i=0;i<12;i++)
  {
    angles[i]=s[i].currentAngle;   
  }
  
   for(int i=0;i<maxDiff;i++)   // write the servo values as sweep in maxDiff millisec * delay()
   {
    for(int j=0;j<12;j++)
    {
        if(s[j].diff<0) //if diff is -ve
        {
          angles[j]= s[j].currentAngle-( ( (i*s[j].absDiff)/maxDiff  )+1 );     
        }
        
        if(s[j].diff>0)// if diff is +ve
        {
          angles[j]= s[j].currentAngle+( ( (i*s[j].absDiff)/maxDiff  ) +1 );  
        }
        s[j].servoWrite( angles[j] );
        //  Serial.print("Servo ");Serial.print(j+1);Serial.print(" position=");Serial.println(angles[j]);      
    }
    // Serial.println("////////////////////////////////////////////// ");
    delay(delayForServos);
   }

  for(int i=0;i<12;i++)
  {
    s[i].currentAngle=angles[i];   
  }
   
 // delay(5000);
/*  for(int i=0;i<12;i++)
  {
    Serial.print("Servo ");Serial.print(i);Serial.print(" curr=");Serial.println(s[i].currAngle);
    Serial.print("Servo ");Serial.print(i);Serial.print(" Target=");Serial.println(s[i].targetAngle);
    Serial.print("Servo ");Serial.print(i);Serial.print(" diff=");Serial.println(s[i].diff);
  }
  delay(5000);
*/
   
}
